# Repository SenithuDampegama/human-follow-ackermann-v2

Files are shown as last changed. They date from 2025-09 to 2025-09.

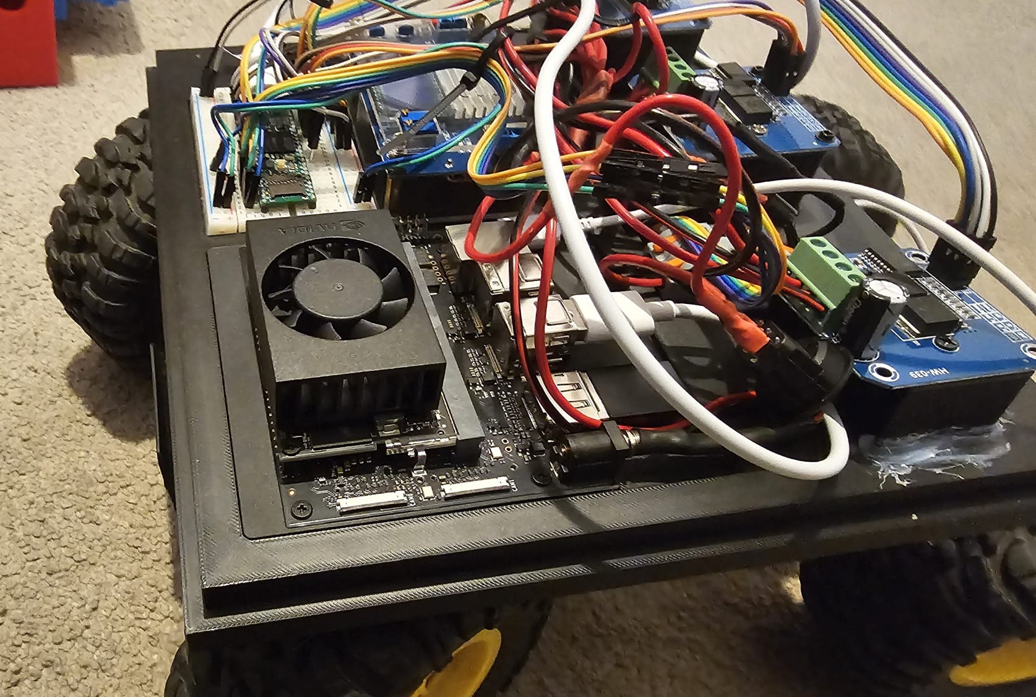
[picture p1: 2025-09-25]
media/Final component placement.jpeg

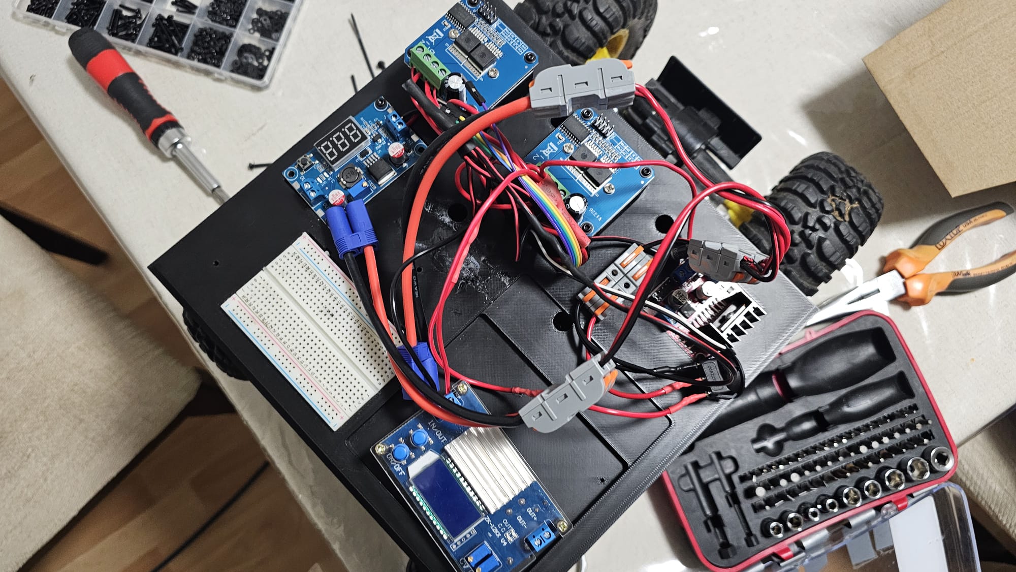
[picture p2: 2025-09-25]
media/assembling 1.jpeg

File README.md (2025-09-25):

# Human‑Following Ackermann v2 — OAK‑D Pro W

> **v2 of the human‑following Ackermann robot.** On‑camera perception with **OAK‑D Pro W** (Spatial MobileNet‑SSD), lightweight **IOU DeepSORT** tracking, and a robust layered control stack (L5 decision FSM on Jetson, L4 ASCII serial to Teensy 4.1). Safe **stationary SEARCH/RECOVER**, preview **RGB + Depth**, and runtime‑tunable steering.

---
Final_look

https://github.com/user-attachments/assets/c350c275-c0d9-4812-8b06-1a35ac1b5258
---

## ✨ Highlights
- **On‑device vision** (OAK‑D Pro W): RGB, StereoDepth (aligned), MobileNet **Spatial** detection (x,y,z in m)
- **Multi‑person lock:** IOU‑only DeepSORT tracker delivers stable `track_id`
- **Layered control:** L5 FSM (INIT→SEARCH→ACQUIRE→FOLLOW→FAULT) → L4 serial → Teensy drivers
- **Safety:** stationary SEARCH/RECOVER (no peeking), bounded runtime (`--max-seconds`), PWM caps
- **Robustness:** serial **auto‑reconnect** on USB drops; optional stable `/dev/teensy` symlink
- **Operator view:** dual preview **RGB + Depth** (scalable window), lock hotkeys `l/r`

---

## 🧱 Repository Layout
```
hf_ackermann/
  app.py                         # CLI entry (STUB/LIVE, OAKD/PINSIGHT/FAKE, tuning)
  control/
    rc_layer4.py                 # L4 serial client (ASCII, OK/DONE/TELEM, reconnect)
    rc_layer5.py                 # L5 decision FSM (stationary SEARCH), steering & distance
  vision/
    vision_oakd_onboard.py       # OAK‑D spatial NN + depth + composite preview
    vision_pinsight_legacy.py    # Legacy PiNSight adapter (fallback)
  tracking/
    deepsort_iou.py              # Lightweight IOU tracker (default)
    deepsort_heavy.py            # Optional wrapper for deep‑sort‑realtime
  tests/
    test_l4_smoke.py             # OK/DONE/TELEM smoke (auto‑skip if no Teensy)
    test_l4_fault.py             # L4 disconnect → auto‑reconnect (mocked)
  RC_firmware_simple/            # Embedded system code
    RC_firmware_simple.ino
    RcBasicCtr.cpp
    RcBasicCtr.h
    RcCompCtr.cpp
    RcCompCtr.h
    RcLinkSimple.cpp
    RcLinkSimple.h
scripts/
  run_stub_oakd.sh               # safe preview (no motion)
  run_live_oakd.sh               # hardware‑in‑loop (wheels‑up first!)
requirements.txt
README.md  (this)
LICENSE    (MIT)
```

---

## 🔧 Hardware
- **Compute:** NVIDIA Jetson (Orin Nano or better)
- **Camera:** OAK‑D Pro W (wide FOV, Myriad X)
- **MCU:** Teensy 4.1 (actuation & safety)
- **Drivers:** BTS7960 (drive), BTS7980 or equivalent (steering)
- **Power:** LiPo + protection; common ground; short, shielded USB to Teensy

> Tip: Keep OAK‑D and motor returns cleanly separated; ferrites on USB help.

---

## 🚀 Setup
```bash
python3 -m venv .venv && source .venv/bin/activate
pip install -r requirements.txt

# (optional) verify OAK‑D
python - <<'PY'
import depthai as dai
with dai.Device() as d:
    print('OAK-D connected:', d.getDeviceName(), d.getMxId())
PY

# serial permissions (Linux)
sudo usermod -aG dialout $USER && newgrp dialout
```

---

## ▶️ Quick Start
### Safe (STUB: no motion)
```bash
./scripts/run_stub_oakd.sh
# or
python -m hf_ackermann.app --mode STUB --vision OAKD --show 1 --max-seconds 8
```

### LIVE (hardware‑in‑loop)
> **Safety:** first runs **wheels‑up** on a stand.
```bash
./scripts/run_live_oakd.sh
# or, explicit port
python -m hf_ackermann.app --mode LIVE --vision OAKD --port /dev/ttyACM0 --show 1 --max-seconds 10
```

**Preview hotkeys:** `l` lock nearest, `r` release, `q/ESC` quit  
*(optional if enabled)* `s` STOP, `c` CENTER

---

## 🧭 Control & Protocols
**L5 FSM:** INIT → **SEARCH** → ACQUIRE → FOLLOW → FAULT  
- **SEARCH/RECOVER:** stationary (STOP + CENTER once), no motion until a valid target appears
- **FOLLOW:** steer by horizontal offset (non‑linear map); hold distance by **depth z** if available else **area**

**L4 (ASCII serial, unchanged):**
```
STOP
CENTER
DRIVE F <pwm> <ms>   | DRIVE B <pwm> <ms>
ARC   L <pwm> <ms> U | ARC R <pwm> <ms> U
```
Replies: `OK`, `DONE <ARC|DRIVE>`, `TELEM drive=… steer=… L=… R=… t=…` (≈5 Hz)

---

## ⚙️ CLI (selected flags)
```
--mode {STUB,LIVE}                --vision {OAKD,FAKE,PINSIGHT}
--port /dev/ttyACM0               --max-seconds 10
--show {0,1}                      --show-scale 0.5

# Steering (turn shaping)
--deadband-x 0.16                 --arc-gamma 1.6
--pwm-turn-min 140                --steer-bias 0.00
--k-arc-left 700  --k-arc-right 820
--cap-left 250    --cap-right 300
--impulse-left 180 --impulse-right 200

# Distance
--target-z 1.2                    # prefer depth (m)
--target-area 0.18 --area-tol 0.04 # fallback via bbox area
```

---

## 🧪 Tests
```bash
pytest -q hf_ackermann/tests   # lightweight unit tests (no hardware needed)
```

---

## 🛟 Safety & Troubleshooting
- Start in **STUB**, then LIVE **wheels‑up**.
- If serial drops mid‑run: system enters **FAULT**, auto‑reconnects, then resumes in SEARCH.
- Permission denied on `/dev/ttyACM*` → add user to `dialout` (see Setup).
- Choppy preview on Jetson → `--show 0` or lower `--show-scale`.

**Stable serial path (optional):** add udev rule for `/dev/teensy` symlink:
```
# /etc/udev/rules.d/99-teensy.rules
SUBSYSTEM=="tty", ATTRS{idVendor}=="16c0", ATTRS{idProduct}=="0483", SYMLINK+="teensy"
# then
sudo udevadm control --reload-rules && sudo udevadm trigger
```
Use with `--port /dev/teensy`.

---

## 🎛️ Tuning Cheatsheet
- **Right turns too soft?** Increase `--k-arc-right`, `--cap-right`, `--impulse-right`; raise `--pwm-turn-min`.
- **Oscillation?** Increase `--deadband-x` (+0.02) or lower `--arc-gamma` (→1.4–1.6).
- **Far off‑center response slow?** Raise `--arc-gamma` (e.g., 1.8).
- **Prefer depth‑first distance:** set `--target-z` (e.g., 1.2 m).

---

## 📄 License
MIT — see `LICENSE`.

## 🙏 Acknowledgements
DepthAI/OAK‑D (Luxonis), Jetson community, Teensy core devs.

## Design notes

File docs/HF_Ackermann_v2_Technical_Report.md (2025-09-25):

# Human-Following Ackermann v2 — OAK-D Pro W Refactor

Author: Senithu (University of Hertfordshire)

Date: 2025-09-23

## Table of Contents
- [Executive Summary](#executive-summary)
- [System Overview](#system-overview)
- [Hardware Summary](#hardware-summary)
- [Software Architecture](#software-architecture)
  - [Vision (OAK-D Onboard)](#vision-oak-d-onboard)
  - [Tracking](#tracking)
  - [L5 FSM (Decision Layer)](#l5-fsm-decision-layer)
  - [L4 Serial Client](#l4-serial-client)
- [Control Parameters](#control-parameters)
  - [Steering and Turn Shaping](#steering-and-turn-shaping)
  - [Distance and Motion](#distance-and-motion)
  - [Safety and Robustness](#safety-and-robustness)
- [Setup & Runbook](#setup--runbook)
- [Validation & Tests](#validation--tests)
- [Tuning Guide](#tuning-guide)
- [Known Limitations & Risks](#known-limitations--risks)
- [Future Work](#future-work)
- [Appendices](#appendices)
  - [A. CLI Flags](#a-cli-flags)
  - [B. Serial Protocol](#b-serial-protocol)
  - [C. Safety Checklist](#c-safety-checklist)

---

## Executive Summary
- Goal: Refactor into a production-ready human-following stack using OAK-D Pro W with on-camera MobileNetSpatialDetectionNetwork, an efficient IOU tracker, and a robust L5 controller targeting a Teensy-based drive system.
- Approach: On-camera spatial detections (RGB-aligned depth), lightweight IOU tracker for sticky IDs, L5 FSM with stationary SEARCH and decisive FOLLOW steering, and L4 serial client with robust auto-reconnect.
- Results: Stable target lock among multiple people, safe stationary SEARCH, decisive right turns via asymmetric tuning, and bounded runtime option for CI/smoke.
- Safety: Default STUB mode, capped drive PWM, stationary SEARCH/RECOVER, robust serial fault handling, and explicit wheels-up first-run guidance.
- Constraints: Layer-4 ASCII protocol unchanged; firmware unmodified; FSM maintained with enhancements (lock, z-based distance, stationary SEARCH).
- Extensibility: Optional heavy DeepSORT wrapper, configurable preview scaling, CLI-tunable steering shaping.

## System Overview
A modular pipeline runs OAK-D spatial detections, tracking, decision-making, and serial control.

```mermaid
flowchart LR
  A[OAK-D Pro W\nRGB + StereoDepth\nSpatial NN 300x300] --> B[Detections\n(bbox, conf, z_m)]
  B --> C[IOU Tracker\nStable Track IDs]
  C --> D[VisionBus\n(offset_x, area, quality,\ntrack_id, z_m)]
  D --> E[L5 FSM\nINIT→SEARCH→ACQUIRE→FOLLOW→FAULT]
  E --> F[L4 Serial Client]
  F --> G[Teensy L3 Firmware]
```

ASCII block (compatibility):

```
OAK-D (RGB, StereoDepth, Spatial NN)
       | detections (bbox, conf, z_m)
       v
  IOU Tracker  --> Track IDs
       v
  VisionBus (offset_x, area, quality, track_id, z_m)
       v
  L5 FSM (INIT→SEARCH→ACQUIRE→FOLLOW→FAULT)
       v
  L4 (ASCII serial)  ==USB==>  Teensy (L3)
```

Repository layout:

```
./hf_ackermann/
  app.py                      # CLI entry point
  control/
    rc_layer4.py              # L4 serial client (ASCII, OK/DONE, TELEM, reconnect)
    rc_layer5.py              # L5 FSM (stationary SEARCH, lock, depth distance, steering shaping)
  tracking/
    deepsort_iou.py           # lightweight IOU-based tracker
    deepsort_heavy.py         # optional wrapper (deep-sort-realtime)
  vision/
    vision_oakd_onboard.py    # OAK-D spatial NN + RGB/Depth composite preview
    vision_pinsight_legacy.py # legacy MobileNetSSD fallback (non-spatial)
  tests/
    test_l4_smoke.py
    test_l4_fault.py
    test_turn_gains.py
scripts/
  run_stub_oakd.sh
  run_live_oakd.sh
requirements.txt
README.md
```

## Hardware Summary
- Compute: NVIDIA Jetson (generic) or equivalent Linux SBC with USB3.
- Vision: Luxonis OAK-D Pro W (RGB + stereo IR + active illumination; wide FOV).
- MCU: Teensy 4.1 running Layer-3 firmware (ASCII serial protocol).
- Drivers/Actuation: e.g., BTS7960 H-bridge motor drivers; Ackermann steering.
- Power: Provide adequate isolation, brownout protection, and EMI mitigation (ferrite beads, star-grounding). Ensure powered USB hub if needed.
- Safety: First runs on a stand (wheels up). Confirm emergency stops. Avoid tether snags.

## Software Architecture

### Vision (OAK-D Onboard)
- Pipeline: ColorCamera (THE_1080_P) with ISP scaling → ImageManip (keepAspect) → MobileNetSpatialDetectionNetwork (300×300) with depth aligned to RGB via StereoDepth.
- Output per detection: bbox, confidence, label, spatialCoordinates → z_m = max(0, z_mm/1000).
- Preview: Composite RGB (annotated) | Depth (false-color TURBO), optional scaling `--show-scale` (default 0.6). Hotkeys: `l` lock nearest, `r` release, `q`/ESC quit.
- Robustness: Stereo preset resolved across DepthAI versions; logs DepthAI version and device MXID.

### Tracking
- IOU-only tracker (deepsort_iou.py): greedy IOU assignment, `max_age`, `min_hits`, and `iou_threshold`. Monotonic, sticky IDs. Low-CPU.
- Optional heavy wrapper (deepsort_heavy.py) if `deep-sort-realtime` is installed; same `.update()` API.

### L5 FSM (Decision Layer)
- States: INIT → SEARCH → ACQUIRE → FOLLOW → FAULT.
- SEARCH/RECOVER: Stationary. On entry, STOP + CENTER once; no arcs or nudges until a confident target appears.
- FOLLOW Steering: Non-linear mapping from offset_x to PWM with tunable exponent `arc_gamma`, minimum PWM, and asymmetric gains/caps/impulses (right-biased by default). Cooldown gated locally (not passed into L4).
- Distance Control: Prefer depth `z_m` toward `target_z_m` (with `z_tol_m` band). If depth unavailable, hold via area setpoint (`target_area`, `area_tol`).
- Target Lock: If a `locked_id` is set, only measurements with that track_id are considered valid; public `lock_target(track_id)`/`release_lock()`.
- Fault Handling: Catch `L4Disconnected`, enter FAULT, stop issuing motion, and attempt reconnect with exponential backoff. On success: STOP + CENTER (resync), clear lock, transition to SEARCH.

### L4 Serial Client
- Protocol (unchanged): Uppercase ASCII commands
  - `STOP`, `CENTER`, `STEER L/R/U`, `DRIVE F/B <pwm> <ms>`, `ARC L/R <pwm> <ms> <U|H>`
  - Replies: `OK <TAG>`, `DONE <ARC|DRIVE>`, `ERR ...`; TELEM lines (e.g., `TELEM drive=.. steer=.. L=.. R=.. t=..`).
- IO: 115200 baud, `timeout≈0.05s`, `ACK timeout≈2s`, DONE wait ≥ max(duration+2.5s, 6s). Auto-detect port preferring “Teensy”.
- Robustness: Catches serial exceptions, marks disconnected, and exposes `_reopen()` to re-establish link and resync.

## Control Parameters

### Steering and Turn Shaping
Defaults (HFParams in `rc_layer5.py`) and CLI overrides (see Appendix):

| Parameter | Default | Description |
|---|---:|---|
| deadband_x | 0.16 | No-steer window on |offset_x| |
| arc_gamma | 1.6 | Exponent shaping for turn intensity |
| pwm_turn_min | 140 | Minimum PWM when issuing a turn |
| k_arc_pwm_left | 700 | Left turn gain |
| k_arc_pwm_right | 820 | Right turn gain (bias to the right) |
| arc_pwm_cap_left | 250 | Left PWM cap |
| arc_pwm_cap_right | 300 | Right PWM cap |
| arc_impulse_ms_left | 180 ms | Left arc impulse duration |
| arc_impulse_ms_right | 200 ms | Right arc impulse duration |
| steer_bias | 0.00 | Static bias (+ shifts to right) |
| cooldown_ms | 90 | Local cooldown after actuation |

### Distance and Motion

| Parameter | Default | Description |
|---|---:|---|
| target_z_m | None | Desired meter range (if set, prefer depth) |
| z_tol_m | 0.15 m | Tolerance band around `target_z_m` |
| target_area | 0.18 | Desired bbox area fraction (fallback) |
| area_tol | 0.04 | Tolerance band for area control |
| k_drive_pwm | 2200 | Drive aggression toward setpoint |
| min_drive_pwm | 120 | Minimum forward PWM |
| max_drive_pwm | 190 (HFParams) / 250 (app default) | Forward PWM cap |
| drive_impulse_ms | 240 ms | Forward impulse duration |
| close_back_pwm | 140 | Reverse PWM when too close |
| close_back_ms | 150 ms | Reverse impulse duration |

### Safety and Robustness

| Parameter | Default | Description |
|---|---:|---|
| loop_hz | 15.0 | L5 control loop rate |
| stale_ms | 300 ms | Stale vision age threshold |
| lost_ms | 700 ms | Time without fresh target to declare loss |
| reconnect backoff | 1→2→4→8→10 s | Exponential backoff in FAULT |
| bounded runtime | `--max-seconds` | Clean exit for CI/smoke runs |

## Setup & Runbook

Environment:

```bash
python -m venv .venv && source .venv/bin/activate
pip install -r requirements.txt
```

OAK-D probe (bounded):

```python
# Quick import check (≤5 s)
from hf_ackermann.vision.vision_oakd_onboard import OAKDSpatial
print("OAKD module import OK")
```

Run commands (examples):

```bash
# STUB (safe; no motion)
python -m hf_ackermann.app --mode STUB --vision OAKD --show 1 --max-seconds 10

# LIVE (Teensy connected; wheels-up)
python -m hf_ackermann.app --mode LIVE --vision OAKD --show 1 --max-seconds 10

# Smaller preview window
python -m hf_ackermann.app --mode STUB --vision OAKD --show 1 --show-scale 0.6 --max-seconds 10
```

## Validation & Tests
- STUB + OAK-D: Observe INIT → SEARCH (stationary STOP+CENTER), then ACQUIRE/FOLLOW when a person enters. Confirm target lock stability among multiple people.
- LIVE (wheels-up): TELEM ~5 Hz; steering/drive impulses within caps; no movement in SEARCH.
- Disconnect/Reconnect: Unplug Teensy during operation → FAULT; logs periodic reconnect attempts, resyncs on success (STOP+CENTER), resumes SEARCH.
- Depth vs Area: With `--target-z` set, verify distance holds using depth; otherwise area-based setpoint.

## Tuning Guide
- Boost right turns:

```bash
--k-arc-right 900 --cap-right 320 --impulse-right 220 --arc-gamma 1.7 --pwm-turn-min 150
```

- Reduce oscillation:
  - Increase `deadband_x` slightly (e.g., 0.18–0.20).
  - Lower `arc_gamma` toward linear (e.g., 1.2–1.4) or reduce gains/caps proportionally.
- Depth jitter:
  - Increase `tau_z_ms` or widen `z_tol_m`.
  - Ensure good lighting/texture; avoid reflective/transparent surfaces.

## Known Limitations & Risks
- Open-loop motion (no encoders): true speed/heading not closed-loop; drift possible.
- Lighting/Depth edge cases: specular/low-texture surfaces can degrade depth.
- Tracker ID swaps: rare with IOU-only; embeddings (heavy) can help when available.
- EMI/USB reliability: mitigate with ferrites and quality cabling; auto-reconnect in software.

## Future Work
- Appearance embeddings with heavy DeepSORT; adaptive association.
- Systemd unit for unattended startup; watchdog monitoring.
- Web UI/telemetry (stream logs, preview, tuning sliders).
- Stable `/dev/teensy` symlink via udev for consistent port naming.

## Appendices

### A. CLI Flags
Extracted from `hf_ackermann/app.py` (defaults shown):

| Flag | Type | Default | Description |
|---|---|---|---|
| --mode | {STUB, LIVE} | STUB | Operating mode |
| --vision | {OAKD, FAKE, PINSIGHT} | OAKD | Vision source |
| --port | str | None | Serial port (auto-detect if None) |
| --fps | int | 30 | Camera FPS |
| --loop-hz | float | 15.0 | L5 loop rate |
| --show | int | 1 | Show preview (1/0) |
| --conf | float | 0.5 | Detection confidence threshold |
| --blob | str | None | MobileNet-SSD blob path (optional) |
| --use-tracker | {iou, heavy} | iou | Tracker implementation |
| --target-area | float | 0.18 | Area setpoint (fallback) |
| --target-z | float | None | Depth setpoint (meters) |
| --verbose | int | 1 | Verbose logging |
| --depth-range | str | "0.3,4.0" | Depth viz near,far (meters) |
| --show-scale | float | 0.6 | Preview display scale |
| --max-seconds | float | None | Bounded runtime for CI/smoke |
| --arc-gamma | float | 1.6 | Non-linearity exponent for \|offset_x\| |
| --pwm-turn-min | int | 140 | Minimum PWM when turning |
| --k-arc-left | int | 700 | Left turn gain |
| --k-arc-right | int | 820 | Right turn gain |
| --cap-left | int | 250 | Left PWM cap |
| --cap-right | int | 300 | Right PWM cap |
| --impulse-left | int | 180 | Left impulse duration (ms) |
| --impulse-right | int | 200 | Right impulse duration (ms) |
| --steer-bias | float | 0.0 | Static bias (+ right) |

### B. Serial Protocol
Examples (ASCII over 115200 baud):

```
Host → Teensy:  DRIVE F 180 1200\n
Teensy → Host:  OK DRIVE
...
Teensy → Host:  DONE DRIVE

Host → Teensy:  ARC R 200 700 U\n
Teensy → Host:  OK ARC
...
Teensy → Host:  DONE ARC

Teensy → Host (async): TELEM drive=0 steer=1 L=123 R=456 t=789012
```

### C. Safety Checklist
- [ ] First power-on with wheels up on a stand.
- [ ] Serial port auto-detected; verify `TELEM` at ~5 Hz in LIVE.
- [ ] Confirm `--show 1` preview overlays and depth composite.
- [ ] Verify stationary SEARCH (no motion until target appears).
- [ ] Confirm forward PWM caps are reasonable for environment.
- [ ] Keep emergency stop within immediate reach.

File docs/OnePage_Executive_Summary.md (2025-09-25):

# One-Page Executive Summary — Human-Following Ackermann v2 (OAK-D Pro W)

Author: Senithu (University of Hertfordshire)  
Date: 2025-09-23

## Overview
This project refactors a human-following Ackermann robot into a clean, production-ready stack centered on the Luxonis OAK-D Pro W. It uses on-camera MobileNetSpatialDetectionNetwork for person detection with depth, a lightweight IOU tracker for stable IDs, and a robust decision layer (L5) that commands a Teensy-based drive via an ASCII serial protocol (L4). The system prioritizes safety (stationary SEARCH mode, capped motion) and reliability (serial auto-reconnect), with runtime-tunable steering and a compact RGB+Depth preview.

## Architecture
- OAK-D Pro W: RGB + StereoDepth aligned to RGB, MobileNet spatial NN (300×300).  
- Tracking: IOU-only tracker with greedy IOU matching; stable, monotonic IDs.  
- L5 FSM: INIT → SEARCH → ACQUIRE → FOLLOW → FAULT. SEARCH is stationary (STOP + CENTER once), FOLLOW uses a non-linear steering model with asymmetric left/right gains and caps; distance uses depth `z_m` if available, else bbox area.  
- L4 Serial: Uppercase ASCII commands (`STOP`, `CENTER`, `DRIVE`, `ARC`, `STEER`) with OK/DONE waits and TELEM parsing. Robust auto-reconnect after transient drops.

## Key Features
- Stationary SEARCH/RECOVER: No motion until a confident target reappears.  
- Decisive steering: Tunable non-linear mapping; asymmetric right-turn boost.  
- Safety: STUB default mode, capped motion, wheels-up first run.  
- Robustness: Serial disconnect handling with exponential backoff and resync.  
- Preview: Side-by-side RGB (annotated) + false-color Depth; `--show-scale` for display size.

## How to Run (Examples)
- STUB (safe; 10s bounded):
```
python -m hf_ackermann.app --mode STUB --vision OAKD --show 1 --max-seconds 10
```
- LIVE (wheels-up; bounded):
```
python -m hf_ackermann.app --mode LIVE --vision OAKD --show 1 --max-seconds 10
```
- Smaller preview window:
```
python -m hf_ackermann.app --mode STUB --vision OAKD --show 1 --show-scale 0.6 --max-seconds 10
```

## Steering Tuning (Runtime Flags)
- Non-linearity and minimum: `--arc-gamma 1.6 --pwm-turn-min 140`
- Asymmetry (right-biased defaults):
```
--k-arc-right 820 --cap-right 300 --impulse-right 200 \
--k-arc-left 700  --cap-left 250  --impulse-left 180
```
- Example right-turn boost:
```
--k-arc-right 900 --cap-right 320 --impulse-right 220 --arc-gamma 1.7 --pwm-turn-min 150
```

## Validation
- STUB: INIT → stationary SEARCH; ACQUIRE/FOLLOW engage when a person enters; lock persists across multi-person scenes.  
- LIVE: TELEM ~5 Hz; capped impulses; no motion in SEARCH.  
- Faults: USB drop → FAULT; periodic reconnect; resync (STOP+CENTER); resume SEARCH.

## Risks & Next Steps
- Risks: Open-loop motion without encoders; depth edge cases (reflective/low-texture surfaces); occasional ID swaps with IOU-only tracking.  
- Next: Optional heavy DeepSORT (embeddings), systemd service for autostart, udev rule for stable `/dev/teensy`, telemetry UI.

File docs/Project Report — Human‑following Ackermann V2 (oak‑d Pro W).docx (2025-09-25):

# Human‑Following Ackermann v2 — Refactor to OAK‑D Pro W

Author: Senithu Dampegama — Robotics & AI Engineer
Date: 23 September 2025
Version: v2 (successor to the Arducam/PiNSight-based v1)

## 0) Executive Summary

- Objective: Upgrade the prior human‑following Ackermann robot (v1) to reliably track one person among many while reducing Jetson load.
- Approach: Offload perception to OAK‑D Pro W (Myriad X) running a Spatial MobileNet‑SSD; add a lightweight IOU DeepSORT tracker; retain the proven L5/L4 layered control with Teensy 4.1 actuation.
- Safety & Robustness: Stationary SEARCH/RECOVER (no motion), serial auto‑reconnect on USB drops, bounded runtime flag for tests, capped PWM, and scalable dual preview (RGB + Depth).
- Results: Stable person lock with low Jetson usage; tighter right turns via asymmetric steering gains and non‑linear mapping; unchanged ASCII protocol to Teensy; clean STUB→LIVE runbooks.
- Deliverables: A reorganized package hf_ackermann/ ready for reuse, plus this report documenting architecture, parameters, tests, and future work.

## 1) Background & Motivation

v1 summary. The previous build transformed a failed RC toy into a research robot: Jetson Orin Nano for perception/decision (L5), Teensy 4.1 for actuation/safety (L3), and a simple ASCII protocol (L4). It followed a single person reliably but could not lock onto one human if multiple people entered the frame.

v2 goals. 1. Resolve multi‑person ambiguity via per‑person IDs.
2. Reduce Jetson load by moving heavy CV to the vision sensor.
3. Preserve the safe, layered control split and the exact L4 ASCII protocol to avoid firmware churn.

Key change: Replace Arducam/PiNSight with OAK‑D Pro W; implement a lightweight, IOU‑only DeepSORT to keep stable track_id while minimizing compute.

## 2) System Architecture (L5→L1)

OAK‑D Pro W ── RGB + StereoDepth + Spatial NN (on‑device)
│ detections {bbox, conf, z_mm}
▼
Tracking (IOU DeepSORT) → selected target {track_id, offx, area, z_m, quality}
▼
L5 (Jetson) Decision FSM INIT → SEARCH → ACQUIRE → FOLLOW → FAULT
│ emits high‑level actions (ARC/DRIVE/STOP/CENTER)
▼
L4 (Jetson) ASCII Serial Client → Teensy 4.1 (safety, PWM bursts, stall guard)
▼
Drivers & Actuators (BTS7960 drive, BTS7980 steering)

What’s new in v2 - On‑device Spatial NN (x,y,z) from OAK‑D; Jetson only does tracking + L5.
- Dual preview: RGB with overlays + depth false‑color (scalable).
- Stationary SEARCH/RECOVER (no peeking) for safety and clarity.
- Asymmetric steering (right boosted) and gamma‑shaped turn mapping.
- Serial auto‑reconnect & bounded runtime for robust testing.

## 3) Hardware Overview

- Compute: NVIDIA Jetson (Orin Nano or better).
- Camera: OAK‑D Pro W (wide FOV), Myriad X.
- Controller: Teensy 4.1 (Cortex‑M7, 600 MHz).
- Drivers: BTS7960 (drive axles), BTS7980 (steering).
- Power: Dual 3S LiPo, separate regulators; common ground; shielded USB to Teensy.

Note: Keep OAK‑D and high‑current returns cleanly separated; add ferrites to USB if needed.

## 4) Software Architecture

### 4.1 Vision (OAK‑D On‑Device)

- Pipeline: ColorCamera 1080p + StereoDepth (aligned to RGB) → MobileNetSpatialDetectionNetwork @ 300×300.
- Outputs per detection: bbox_px, confidence, label, spatialCoordinates.{x,y,z} in mm.
- VisionBus payload to L5: {track_id, offx∈[-1..1], area∈[0..1], quality, z_m (m), ts}.
- Preview (when enabled): Composite window [RGB annotated | Depth false‑color], scalable via --show-scale.
- Hotkeys: l lock nearest, r release, q/ESC quit (optional s STOP, c CENTER if wired).

### 4.2 Tracking (Lightweight DeepSORT)

- IOU‑only association with max_age, iou_threshold, hit_streak → sticky IDs at minimal compute cost.
- Optional heavy wrapper (deep‑sort‑realtime) available but off by default on Jetson.

### 4.3 Decision (L5) — FSM

States: INIT → SEARCH → ACQUIRE → FOLLOW → FAULT - SEARCH / RECOVER: stationary; on entry: STOP + CENTER once; wait for a valid target.
- ACQUIRE: quick steering impulses to bring target toward center; short forward nudges if far.
- FOLLOW: - Steering: non‑linear mapping from |offx| with exponent arc_gamma and a minimum turn PWM; asymmetric left/right gains & caps (right boosted).
- Distance: prefer depth z_m (target‑z), else area (target‑area ± tol).
- FAULT: triggered by L4 disconnects; L5 stops issuing motion, then attempts auto‑reconnect with backoff; on success: STOP + CENTER and resume SEARCH.

### 4.4 Interface (L4) — ASCII Protocol (unchanged)

- Commands: STOP, CENTER, DRIVE F|B <pwm> <ms>, ARC L|R <pwm> <ms> <U|H>.
- Replies: OK, DONE <ARC|DRIVE>, ERR <…>, TELEM drive=<…> steer=<…> L=<…> R=<…> t=<…>.
- Timing: 115200 baud; read timeout ≈ 0.05 s; cmd timeout ≈ 2 s; DONE timeout ≈ 3 s (or by duration).
- Robustness: auto‑detect Teensy; auto‑reconnect on SerialException; resume in SEARCH.

## 5) Repository Layout (v2)

hf_ackermann/
app.py # CLI entry: STUB/LIVE, vision source, tuning flags
control/
rc_layer4.py # L4 serial client (ASCII, OK/DONE/TELEM, reconnect)
rc_layer5.py # L5 FSM (stationary SEARCH), steering shaping, distance logic
vision/
vision_oakd_onboard.py # OAK‑D spatial NN + depth + composite preview
vision_pinsight_legacy.py # Legacy fallback (non‑spatial)
tracking/
deepsort_iou.py # Lightweight IOU tracker (default)
deepsort_heavy.py # Optional wrapper for deep‑sort‑realtime
tests/
test_l4_smoke.py # OK/DONE/TELEM smoke
test_l4_fault.py # L4 disconnect → auto‑reconnect (mocked)
scripts/
run_stub_oakd.sh # safe preview, no motion
run_live_oakd.sh # hardware‑in‑loop (wheels‑up first!)
requirements.txt, README.md, LICENSE

## 6) Interfaces & Protocols

### 6.1 Command Protocol (Jetson → Teensy)

STOP\n
CENTER\n
DRIVE F 190 240\n
DRIVE B 140 150\n
ARC L 220 180 U\n
ARC R 220 180 U\n

### 6.2 Telemetry Protocol (Teensy → Jetson)

OK\n
DONE DRIVE\n
TELEM drive=1 steer=2 L=497 R=1022 t=25090824\n

drive/steer are state codes; L/R are sensor counts; t is uptime ms.

## 7) Control Parameters (defaults)

### 7.1 Steering & Turn Shaping

Parameter | Default | Purpose
deadband_x | 0.16 | Ignore small offsets to avoid chatter
arc_gamma | 1.6 | Non‑linear turn shaping for large errors
pwm_turn_min | 140 | Enforce decisive minimum turn
k_arc_pwm_left | 700 | Left turn gain
k_arc_pwm_right | 820 | Right turn boosted
arc_pwm_cap_left | 250 | Max left arc PWM
arc_pwm_cap_right | 300 | Max right arc PWM
arc_impulse_ms_left | 180 ms | Left arc duration
arc_impulse_ms_right | 200 ms | Right arc duration
steer_bias | 0.00 | Optional static offset (normalize drift)

### 7.2 Distance & Motion

Parameter | Default | Purpose
target_z_m | (off) | Preferred distance (m) if depth available
target_area | 0.18 | Fallback distance via bbox area
area_tol | 0.04 | Area band around target
k_drive_pwm | 2200 | Forward PWM gain (capped)
max_drive_pwm | 190 | Safety cap for drive
drive_impulse_ms | 240 ms | Forward impulse duration
back_pwm | 140 | Reverse PWM for back‑off
back_impulse_ms | 150 ms | Reverse impulse duration

### 7.3 Robustness

Parameter | Default | Notes
search_mode | idle | SEARCH/RECOVER are stationary
--show-scale | 0.5–0.6 | Smaller preview window
--max-seconds | (off) | Bounded runtime for tests

All are exposed via CLI flags in app.py for runtime tuning.

## 8) Setup & Runbook

### 8.1 Environment

python3 -m venv .venv && source .venv/bin/activate
pip install -r requirements.txt

OAK‑D probe

python - <<'PY'
import depthai as dai
with dai.Device() as d:
print('OAK-D connected:', d.getDeviceName(), d.getMxId())
PY

### 8.2 STUB (safe, no motion)

./scripts/run_stub_oakd.sh
# or
python -m hf_ackermann.app --mode STUB --vision OAKD --show 1 --max-seconds 8

### 8.3 LIVE (hardware‑in‑loop)

Safety: first runs wheels‑up on a stand; ensure serial permissions (dialout).

./scripts/run_live_oakd.sh
# or
python -m hf_ackermann.app --mode LIVE --vision OAKD --show 1 --max-seconds 10

If auto‑detect fails: --port /dev/ttyACM0 (or a udev symlink /dev/teensy).

## 9) Validation & Observations

- Stationary SEARCH: verified — no ARC/DRIVE while waiting; transitions to ACQUIRE on fresh target.
- FOLLOW: decisive turns, especially to the right (boosted gains/caps); depth‑preferred distance with smooth back‑off when close.
- Serial robustness: induced disconnects yield [FAULT] → auto‑reconnect → STOP + CENTER → back to SEARCH without crash.
- Multi‑person: lock persists via track_id; l/r hotkeys control target selection.

Representative telemetry

TELEM drive=1 steer=2 L=497 R=1022 t=25090824
[FOLLOW] steer arcright pwm=220
TELEM drive=1 steer=2 L=526 R=1021 t=25091024
[FOLLOW] stale → center once
...

## 10) Risk & Limitations

- No wheel encoders → open‑loop velocity; rely on depth/area and impulses.
- Donor wiring caps drive PWM to 190 for thermal safety; revisit after loom upgrade.
- IOU‑only tracker can ID‑swap under heavy, long occlusions (lock + stationary SEARCH mitigates most cases).
- Depth noise possible in strong sun/low‑texture scenes; consider median filtering or depth caps.

## 11) Tuning Guide

- Right turns weak? Increase --k-arc-right, --cap-right, --impulse-right; optionally raise --pwm-turn-min and --arc-gamma.
- Over‑steer/oscillation? Increase --deadband-x by +0.02 or lower --arc-gamma (1.4–1.6).
- Far off‑center? Increase --arc-gamma (e.g., 1.8) and/or --pwm-turn-min.
- Depth‑first following: set --target-z 1.2 (example), otherwise use --target-area/--area-tol.

## 12) Future Work

- Appearance embeddings (heavy DeepSORT) when compute budget allows.
- Add encoders + basic odometry; consider SLAM for navigation.
- Wiring/driver upgrades to lift PWM caps safely.
- systemd auto‑start (STUB by default), simple web telemetry, and a udev rule for /dev/teensy.

## Appendix A — CLI Flags (selected)

--mode {STUB,LIVE}
--vision {OAKD,FAKE,PINSIGHT}
--port /dev/ttyACM0
--show {0,1} --show-scale 0.5
--max-seconds 10

# Steering & distance
--deadband-x 0.16
--arc-gamma 1.6
--pwm-turn-min 140
--k-arc-left 700 --k-arc-right 820
--cap-left 250 --cap-right 300
--impulse-left 180 --impulse-right 200
--steer-bias 0.00
--target-z 1.2
--target-area 0.18 --area-tol 0.04

## Appendix B — Serial Protocol Examples

> ARC R 220 180 U
< OK
< DONE ARC

> DRIVE F 190 240
< OK
< DONE DRIVE

< TELEM drive=1 steer=2 L=615 R=1022 t=25091724

## Appendix C — Safety Checklist

- Start in STUB; only then run LIVE (wheels‑up).
- Use --max-seconds during tests to avoid endless runs.
- Confirm TELEM rate (~5 Hz), caps (max_drive_pwm, arc_pwm_cap_*).
- Verify auto‑reconnect path by briefly replugging USB (observe FAULT→recover).
- Keep grounds clean; use short, shielded USB.

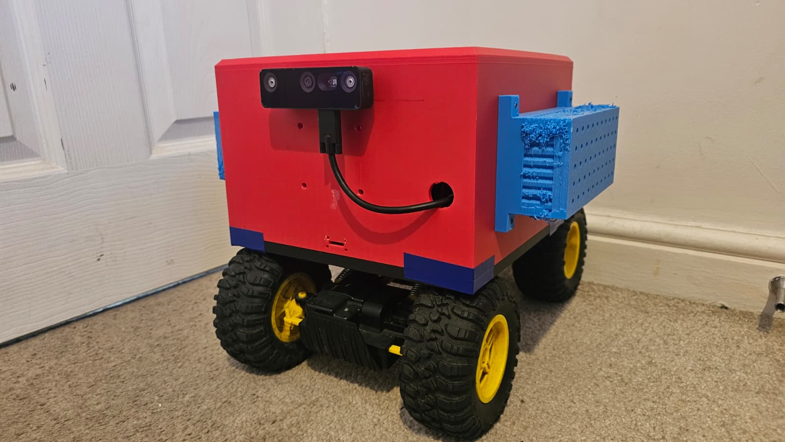
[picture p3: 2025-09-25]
media/front2.jpeg

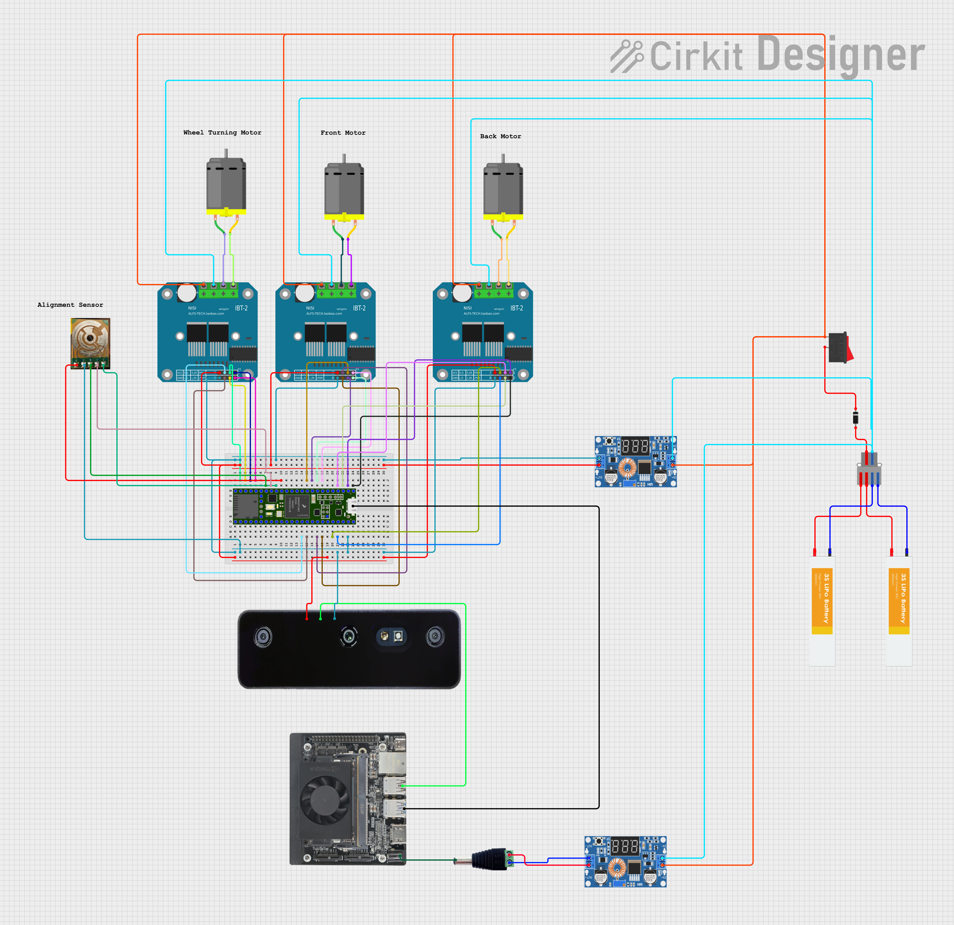
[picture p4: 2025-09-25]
docs/circuit_image.png

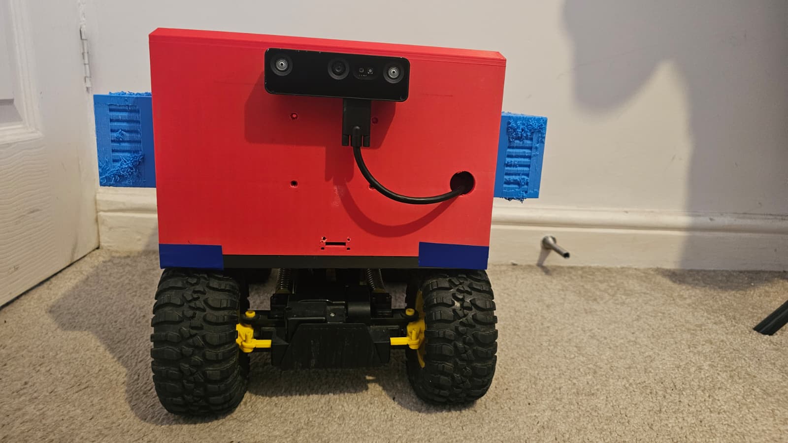
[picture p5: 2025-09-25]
media/front.jpeg

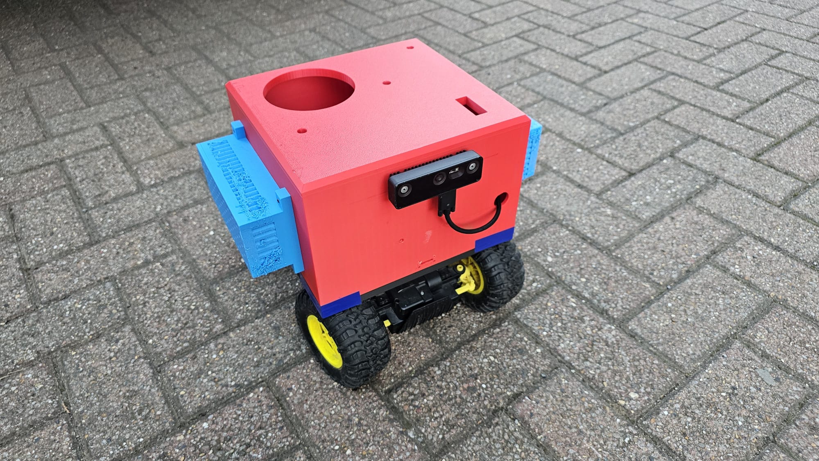
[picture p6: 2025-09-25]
media/Final_look.jpeg

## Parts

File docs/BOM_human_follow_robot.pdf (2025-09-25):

# Bill of Materials — Human‑Following Ackermann

v2

Item | Part Name | Description / Specs | Qty | Supplier /
| | | | Part No. | Notes
E1 | Teensy 4.1 | 600 MHz ARM Cortex-
| | M7 MCU, 55 I/O pins | 1 | PJRC | Main controller
| | | | | (Layer 1–3)
E2 | Jetson Orin Nano
| 8GB Dev Kit | 1024-core GPU, 8GB
| | RAM, AI compute | 1 | NVIDIA | Vision & AI
| | | | | processing
E3 | Motor Driver –
| BTS7960 | 43 A high-power H-
| | bridge | 2 | Amazon /
| | | | eBay | Front & rear drive
E4 | Motor Driver –
| BTS7980 | 55 A high-power H-
| | bridge | 1 | Amazon /
| | | | eBay | Steering control
E5 | OAK-D Pro Wide | USB AI camera module | 1 | Luxonis | Runs vision
| | | | | pipeline
E6 | LiPo Battery 3S 11.1V
| (≥5000 mAh) | Main power source | 2 | Hobby store | Power for drive &
| | | | | compute
E7 | Buck Converter
| (12V→5V, 5A) | Power regulation | 2 | Amazon | Jetson &
| | | | | peripherals
E8 | Step-Down Regulator
| (12V→7.4V) | Steering driver supply | 1 | Amazon | Clean supply for
| | | | | steering
E9 | XT60 Connectors +
| Harness | High-current connectors | 6 | Amazon | Power distribution
E10 | 12 AWG Silicone Wire
| (red/black) | High-current wiring | 5 | Amazon | Drive power loom
E11 | 18 AWG Wire (signal) | Low-current wiring | 10 | Amazon | Signals/logic
E12 | Inline Fuse Holder +
| Fuses | Protection | 2 | Amazon | Battery safety
E13 | Ferrite USB-C Bead | EMI suppression | 2 | Amazon | Teensy/OAK-D
| | | | | USB
E14 | USB-C Cable (short,
shielded) | Data + power for OAK-D | 1 | Anker | Prefer 0.5 m shielded

1

Item | Part Name | Description / Specs | Qty

Supplier /
Part No.

Notes

E15

USB Micro/Type-A
Cable (shielded) | Teensy connection | 1 | Anker | Short, shielded

E16

Chassis Mounts &

Brackets | Mechanical mounts | 1 | Custom | 3D prints /
| | | | aluminum

E17

Wheels/Tracks

(Ackermann) | Locomotion | 4 | Donor RC | Usable donor
| | | | parts

E18

Current Sensor

(optional) | Stall monitoring | 2 | Pololu | Firmware support
| | | | optional

E19

RC Kill Switch
(optional) | Emergency stop | 1 | Spektrum | Safety accessory
E20 | Misc. Hardware | Screws, standoffs,
| heatshrink | 1 | — | Build
| | | | consumables

Note: Quantities and suppliers reflect the reference build; adjust to your inventory.

2

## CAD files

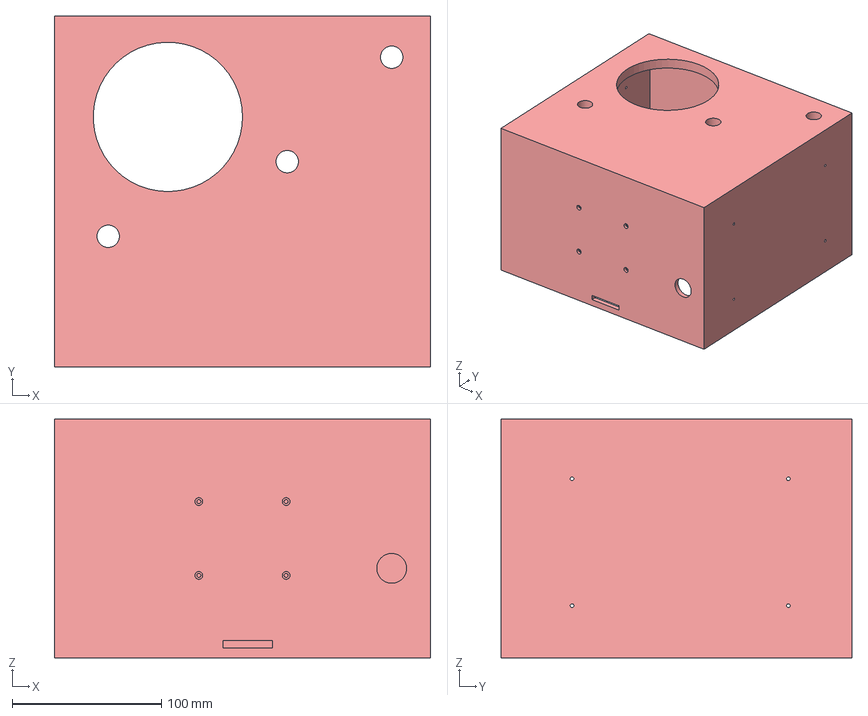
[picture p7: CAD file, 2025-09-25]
cad/Main_Lid.step
252.0 x 235.0 x 160.0 mm

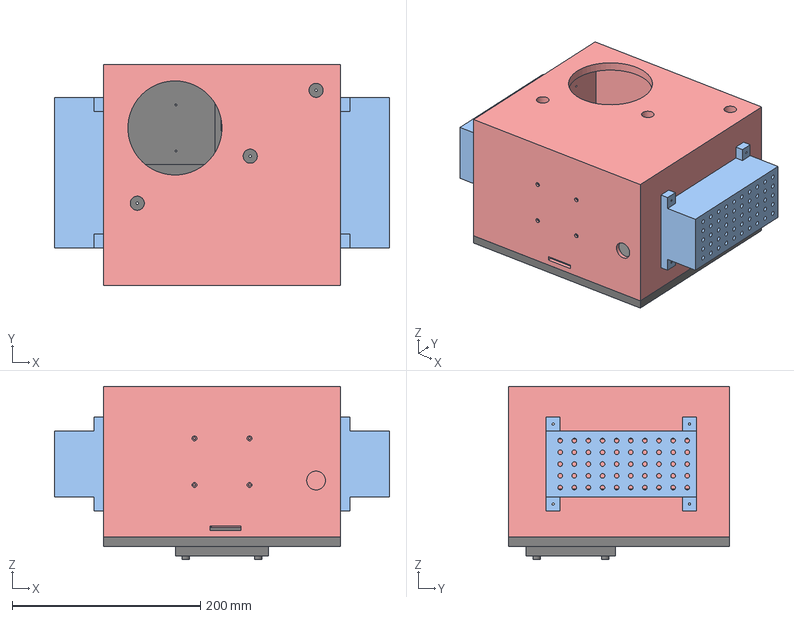
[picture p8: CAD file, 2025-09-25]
cad/Assembly.step
356.0 x 235.0 x 184.0 mm
battery lid x 2
Base
main lid

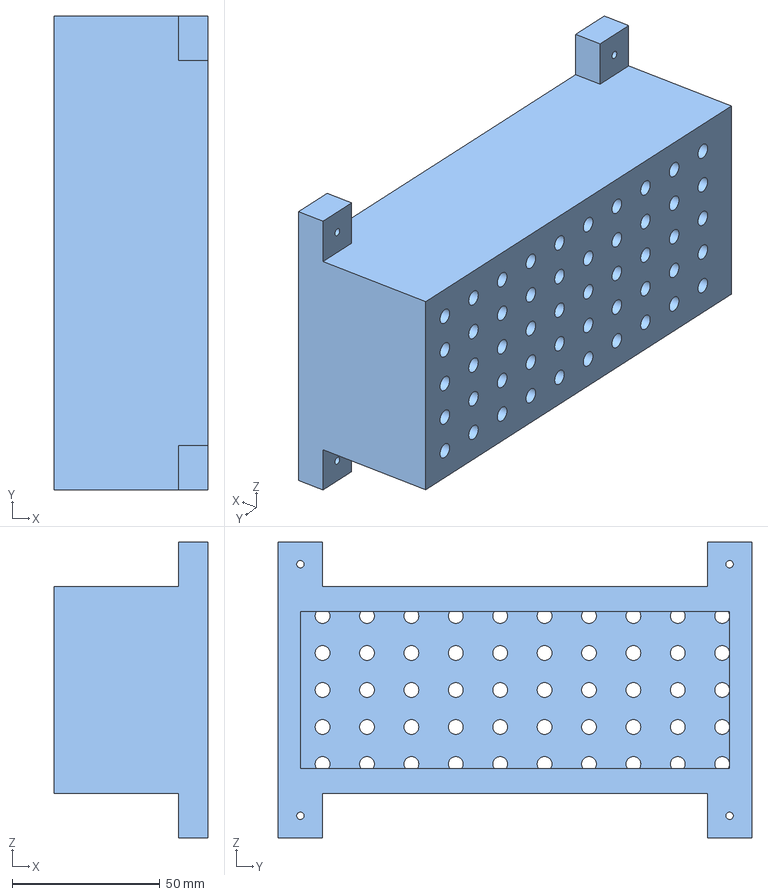
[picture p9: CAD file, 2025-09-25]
cad/Battery_Lid.step
52.0 x 160.0 x 100.0 mm

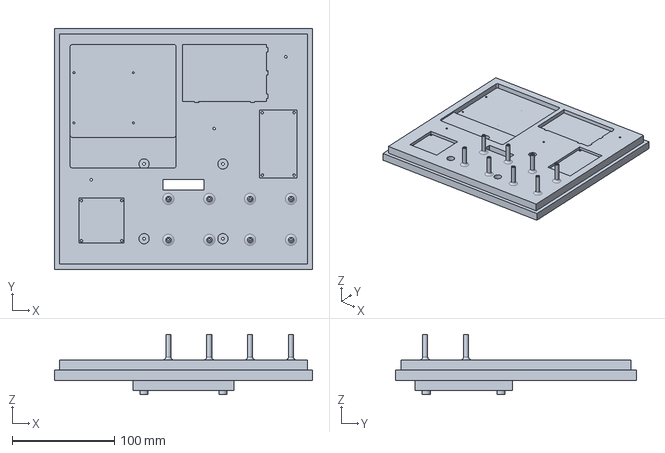
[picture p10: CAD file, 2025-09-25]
cad/Base.step
252.0 x 235.0 x 59.0 mm

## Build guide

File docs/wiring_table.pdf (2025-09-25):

# Wiring Table — Human Follow Robot

Controller: Teensy 4.1
Power: Dual LiPo → Buck Converters → Logic & Jetson

## Front Axle — Motor Drivers (BTS7960)

Pin | Signal | Destination Pin
5 | FL_PWM | PWM-L
6 | FR_PWM | PWM-R
7 | FL_EN | EN-L
8 | FR_EN | EN-R
A6 | FL_IS | IS-L
A5 | FR_IS | IS-R

## Rear Axle — Motor Drivers (BTS7960)

Pin | Signal | Destination Pin
0 | BL_PWM | PWM-L
1 | BR_PWM | PWM-R
2 | BL_EN | EN-L
3 | BR_EN | EN-R
A9 | BL_IS | IS-L
A8 | BR_IS | IS-R

## Steering — Motor Driver (BTS7980)

Pin | Signal | Destination Pin
28 | TL_PWM | PWM-L
29 | TR_PWM | PWM-R
30 | TL_EN | EN-L
31 | TR_EN | EN-R
A3 | TL_IS | IS-L
A2 | TR_IS | IS-R

## Wheel Alignment Sensor

Pin | Signal | Destination
A10 | Left | Alignment Sensor Left Output
A11 | Middle | Alignment Sensor Middle Output

A12 | Right | Alignment Sensor Right Output

## Power & Comms

Pin | Signal | Destination
VIN | +Vcc | 5 V Logic rail from buck converter
GND | Ground | Common GND to all modules
USB | Data | Jetson Orin Nano

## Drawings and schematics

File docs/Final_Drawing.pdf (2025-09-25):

A

2 | 3 | 4 | 5 | 6 | 7 | 8

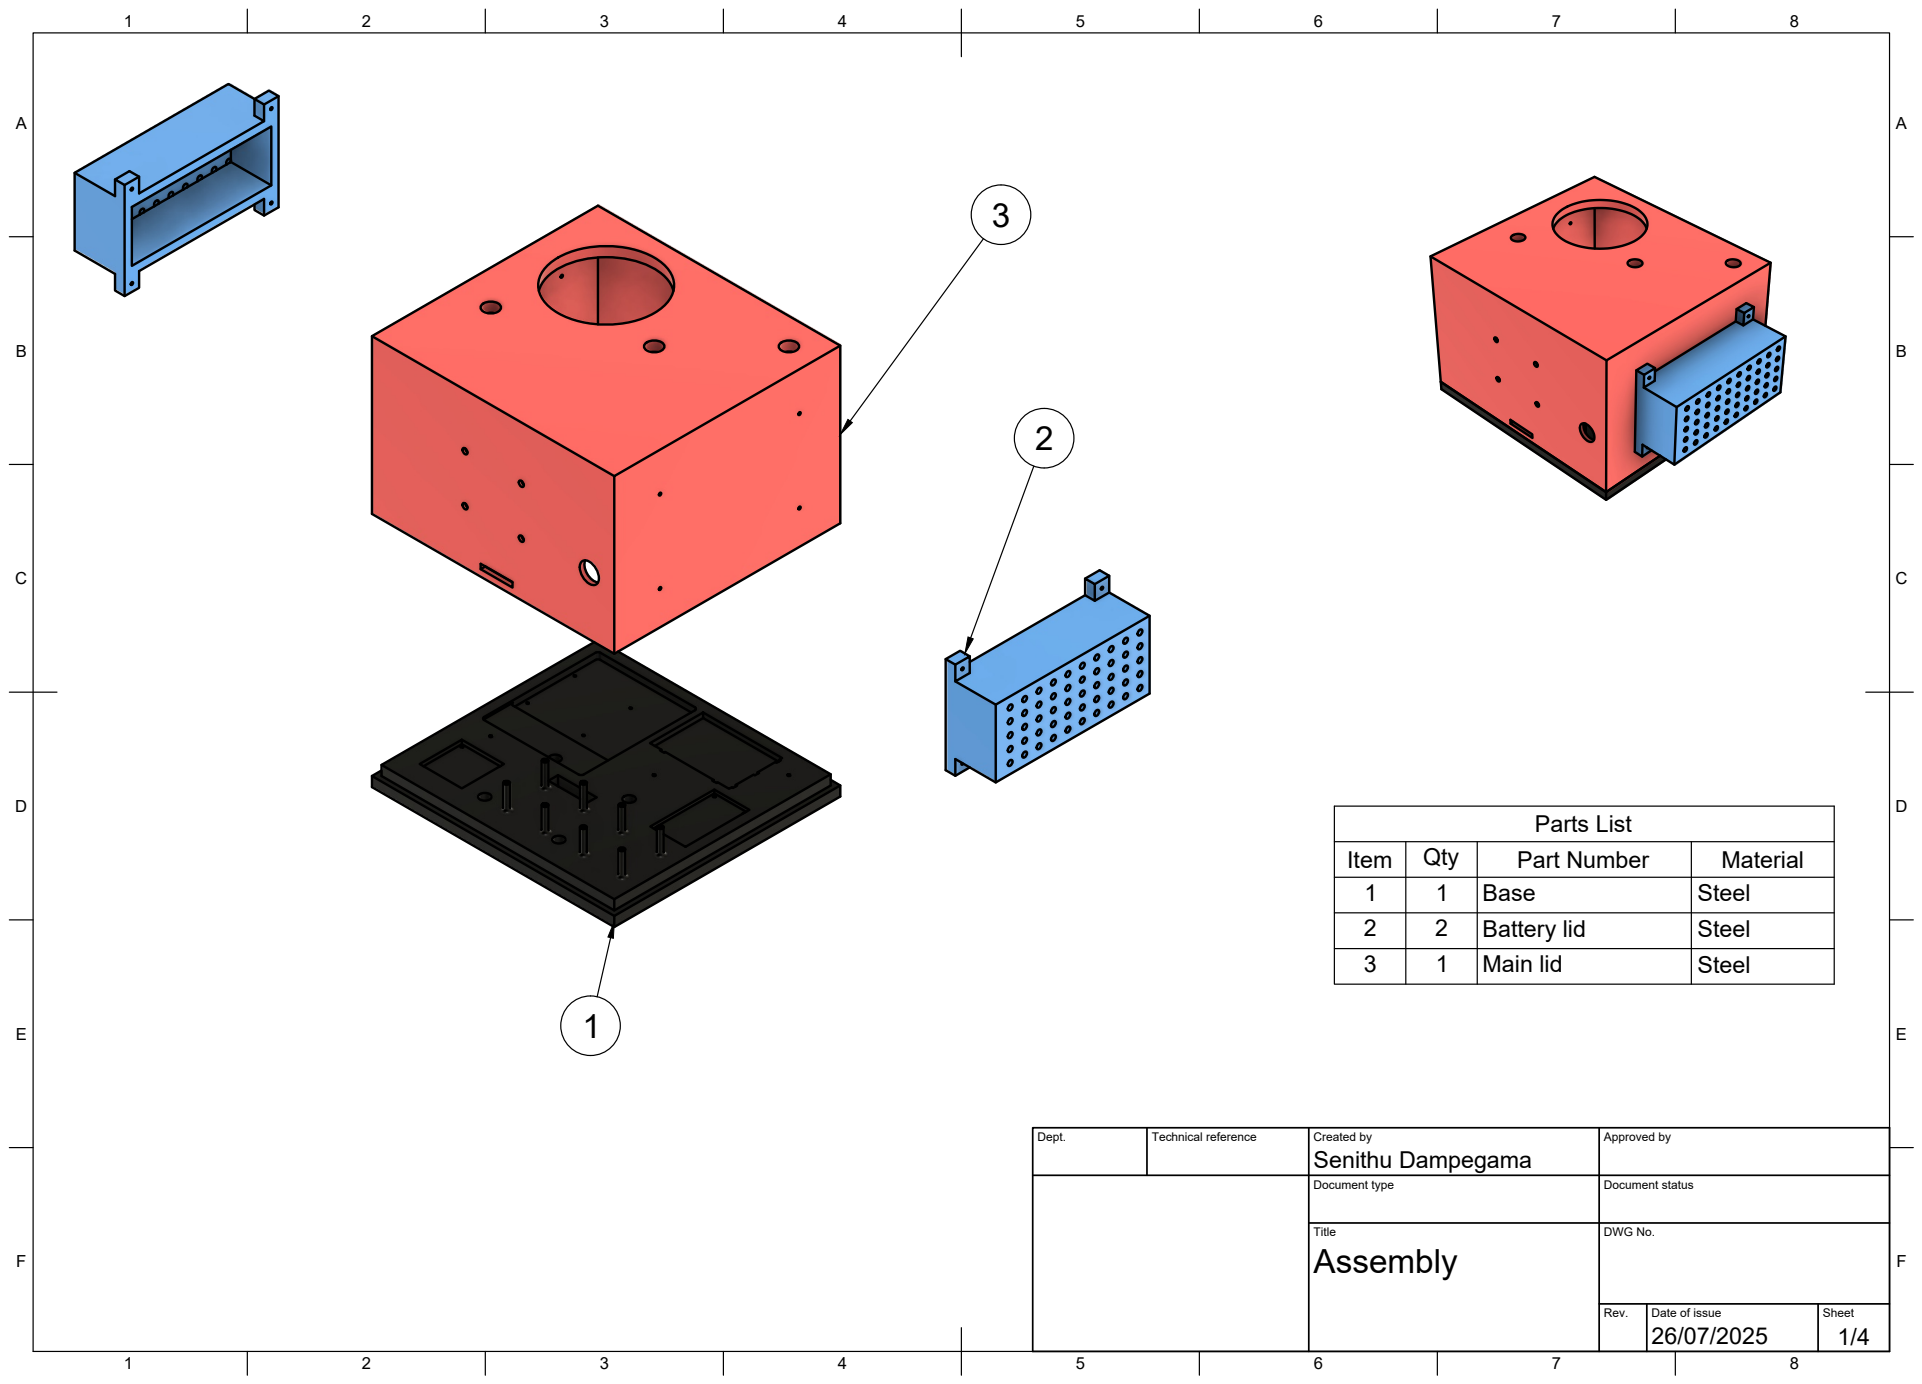
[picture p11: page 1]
Dept.; Technical reference; Created by; Approved by; Document type; Document status; Title; DWG No.; Rev.; Date of issue; Sheet; Assembly; Senithu Dampegama; Parts List; Item; Qty; Part Number; Material; Base; Steel; Battery lid; Main lid

A

A

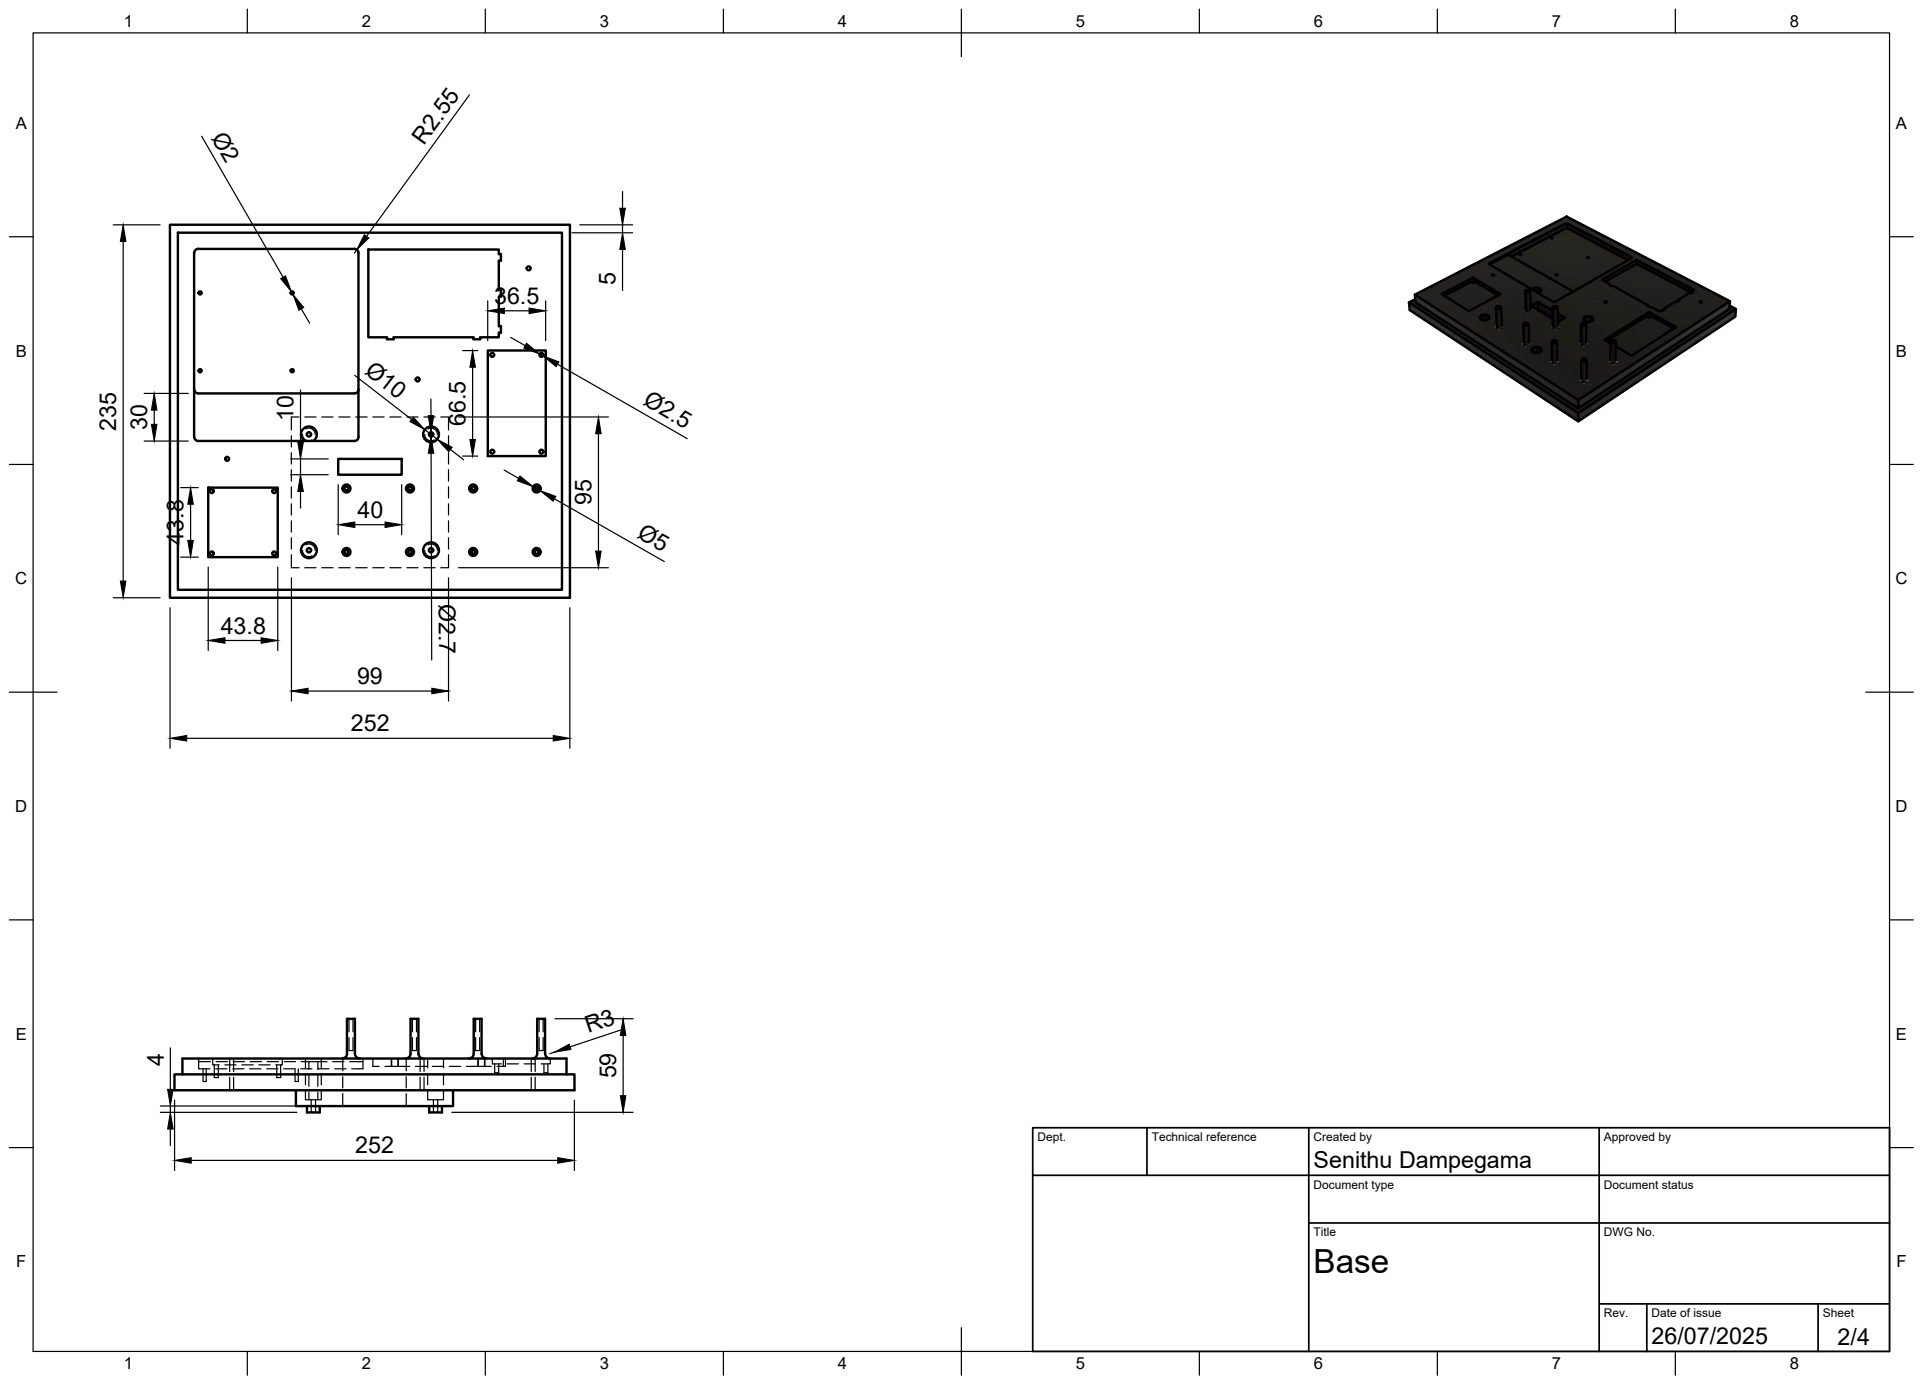
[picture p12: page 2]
Dept.; Technical reference; Created by; Approved by; Document type; Document status; Title; DWG No.; Base; Senithu Dampegama; 252 ²³⁵

A

A

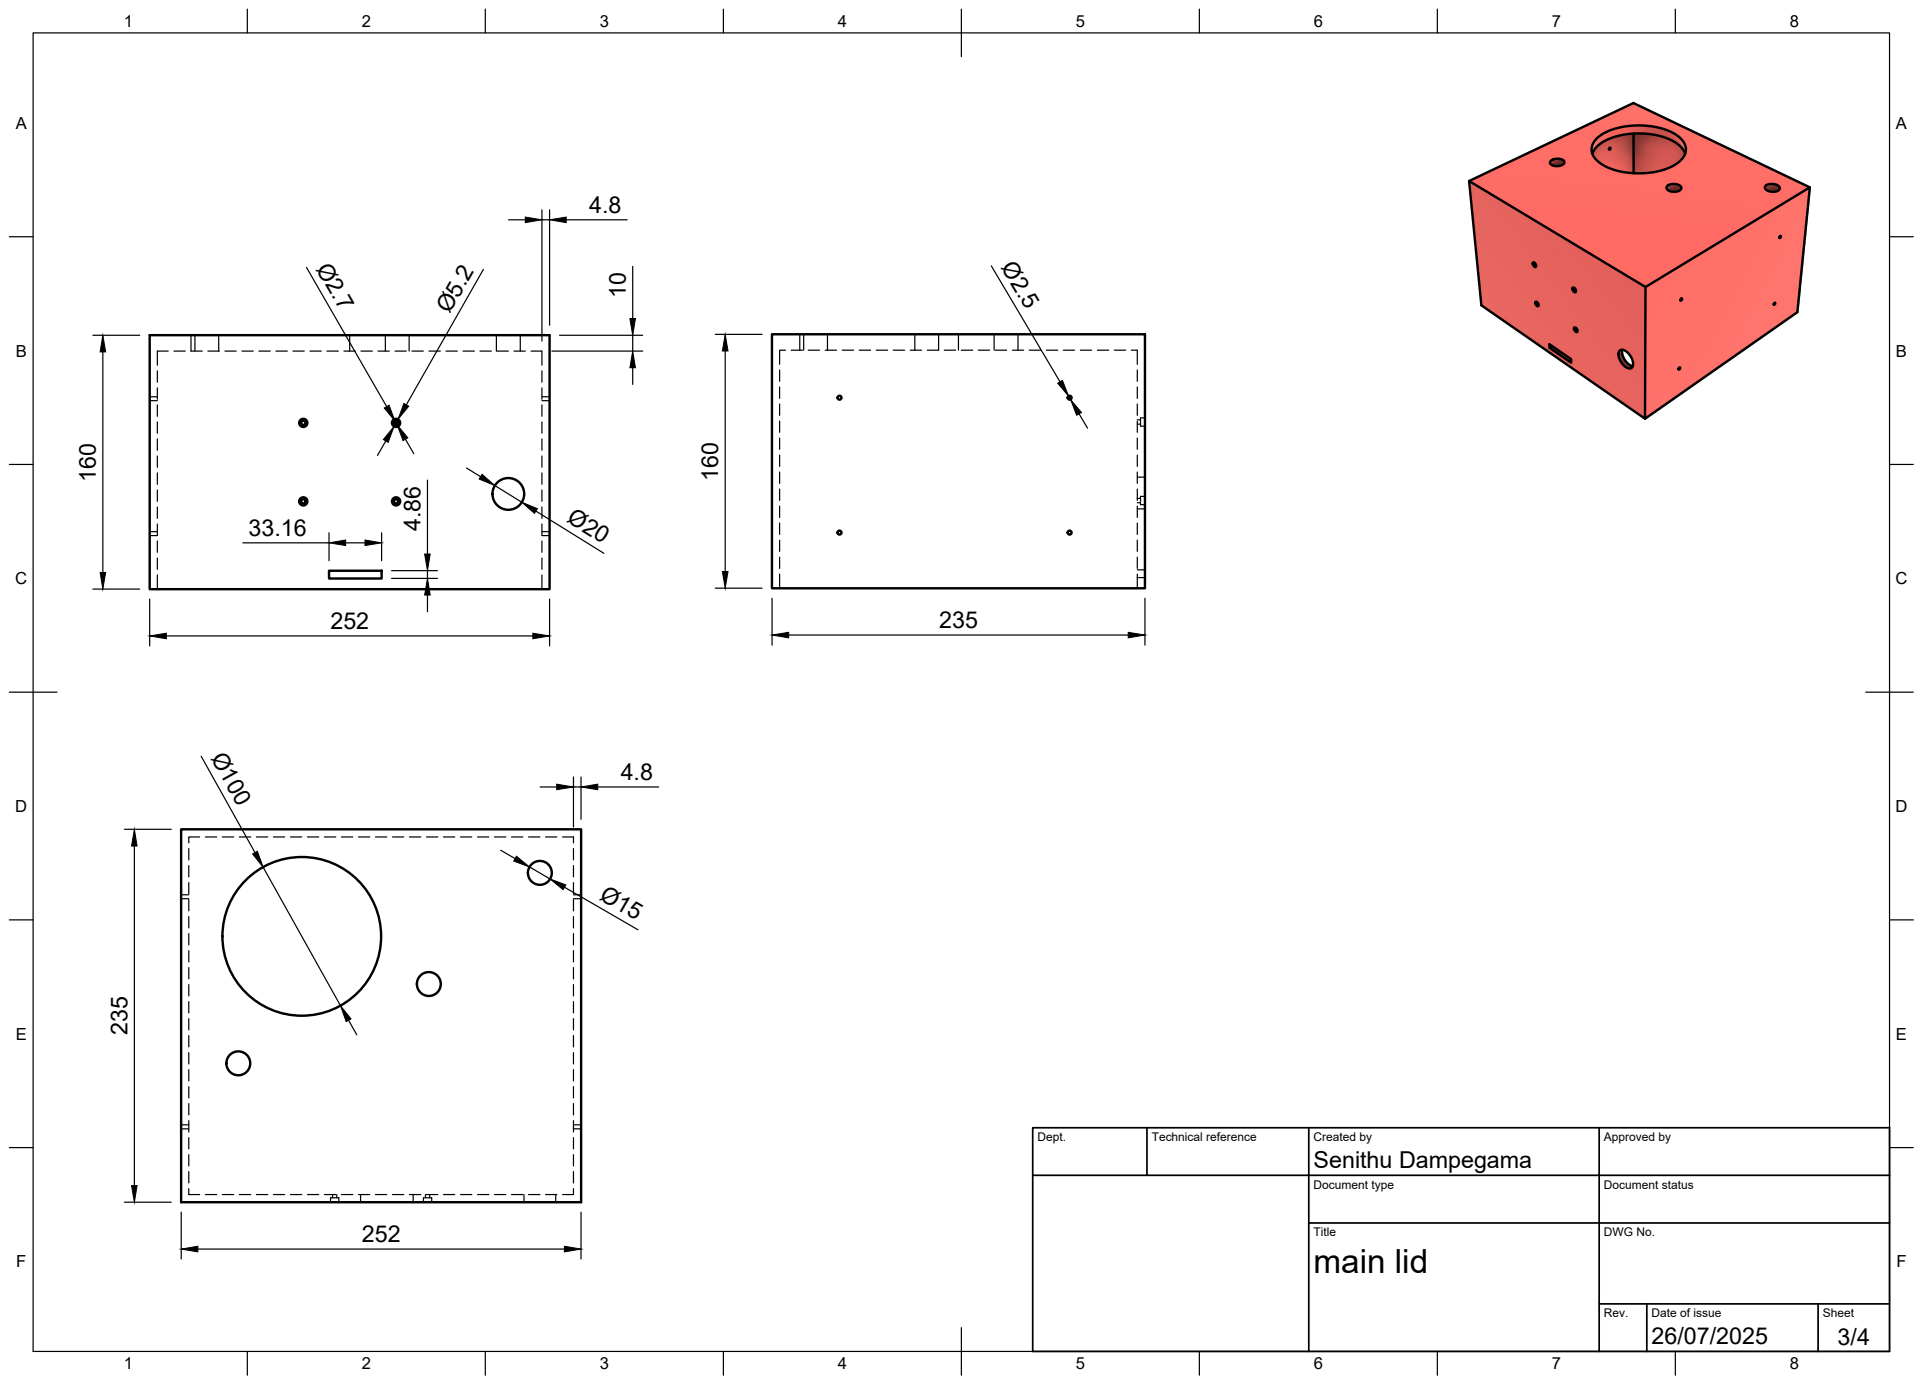
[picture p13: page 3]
Dept.; Technical reference; Created by; Approved by; Document type; Document status; Title; DWG No.; main lid; Senithu Dampegama; 252 ²³⁵; 252 ¹⁶⁰; 235 ¹⁶⁰

A

A

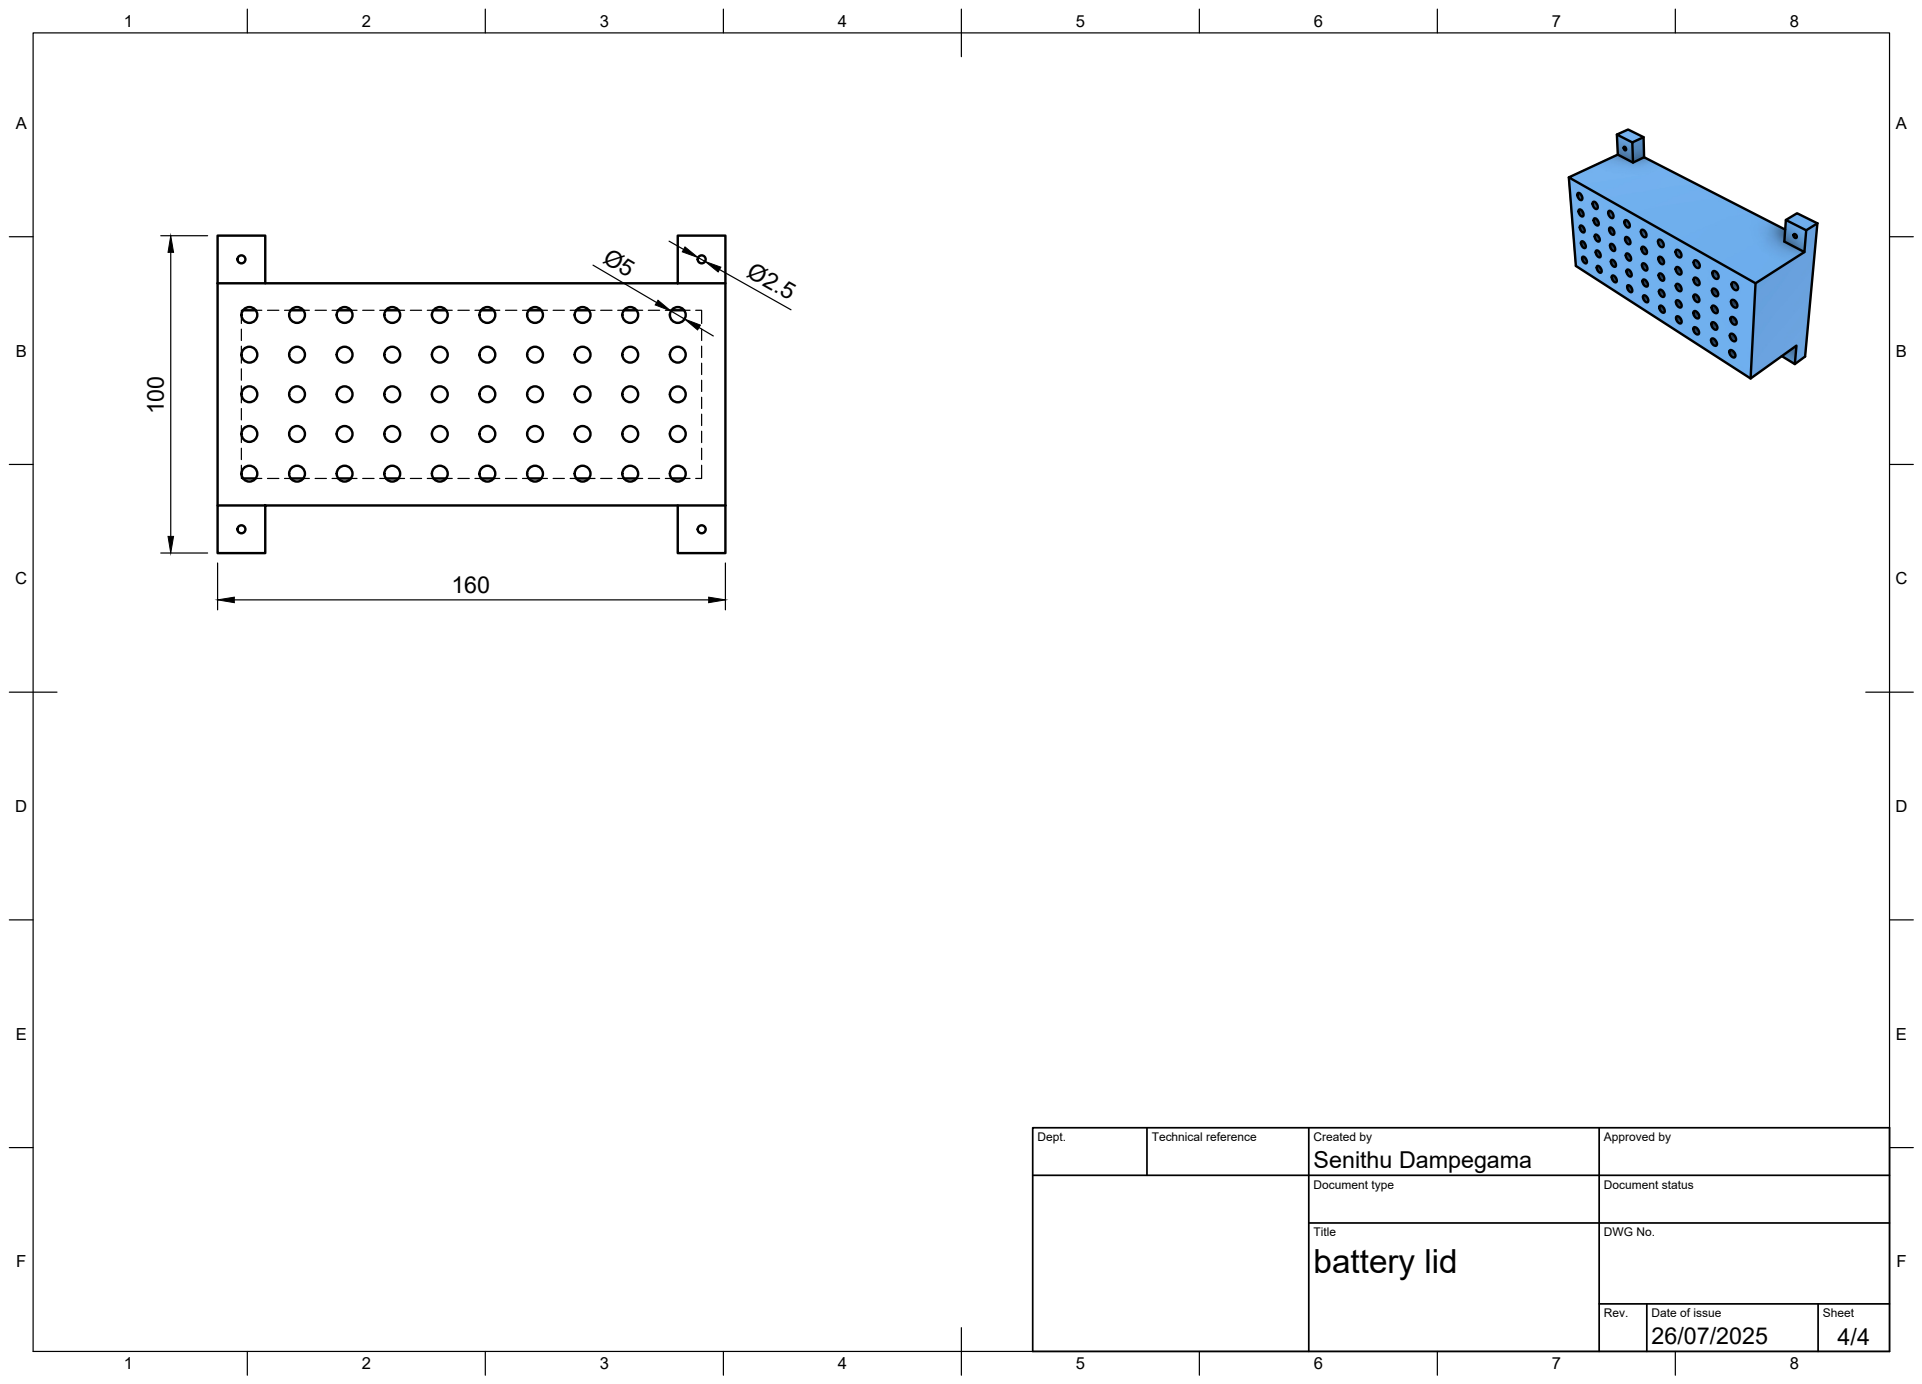
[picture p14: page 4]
Dept.; Technical reference; Created by; Approved by; Document type; Document status; Title; DWG No.; battery lid; Senithu Dampegama; 160 ¹⁰⁰

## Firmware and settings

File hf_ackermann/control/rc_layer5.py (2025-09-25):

#!/usr/bin/env python3
# -*- coding: utf-8 -*-
"""
Layer 5 — Decision Maker for Human-Follow (Ackermann crawler) with directional loss recovery
and optional target lock + depth-aware distance.

State machine: INIT → SEARCH → ACQUIRE → FOLLOW → FAULT

Vision interface (VisionBus.publish):
  - offset_x: float in [-1..+1]
  - area: float in [0..1]
  - quality: float in [0..1]
  - track_id: Optional[int]
  - z_m: Optional[float]  (meters; if provided and params.target_z_m is set, used for distance)

L4 contract: unchanged; we only call RcLayer4.send() with uppercase ASCII commands.
Cooldown gating is local to L5 and is NOT forwarded to L4.
"""

from __future__ import annotations
import time
import threading
from dataclasses import dataclass
from enum import Enum, auto
from typing import Optional, Dict, Any, Literal

# Local import within package
from .rc_layer4 import RcLayer4, L4Error, L4Disconnected


# ---------------------------- Parameters ----------------------------

@dataclass
class HFParams:
    # Steering (ARC)
    deadband_x: float = 0.16          # tuned defaults are provided by app
    k_arc_pwm:   int  = 700
    min_arc_pwm: int  = 120
    max_arc_pwm: int  = 220
    arc_impulse_ms: int = 180

    # Distance (DRIVE) — area based unless target_z_m is set and vision provides z_m
    target_area: float = 0.18
    area_tol:    float = 0.04
    k_drive_pwm: int   = 2200
    min_drive_pwm: int = 120
    max_drive_pwm: int = 190
    drive_impulse_ms: int = 240

    # Depth-based distance control (optional)
    target_z_m: Optional[float] = None    # if set, use z_m to regulate distance
    z_tol_m: float = 0.15                 # +/- tolerance window around target_z_m

    # Back-off when too close
    close_back_pwm: int = 140
    close_back_ms:  int = 150

    # Freshness & loop
    stale_ms:   int   = 300
    lost_ms:    int   = 700
    loop_hz:    float = 15.0
    cooldown_ms:int   = 90

    # Filters (1-pole IIR)
    tau_x_ms:   int = 180
    tau_area_ms:int = 220
    tau_z_ms:   int = 220

    # Logging
    verbose: bool = True

    # Directional recovery on loss
    recover_enable:      bool = True
    recover_max_ms:      int  = 3000
    recover_arc_pwm:     int  = 250
    recover_impulse_ms:  int  = 180
    recover_cooldown_ms: int  = 120
    recover_min_abs_x:   float = 0.10
    quality_gate:        float = 0.60

    # Turning shape & minimum
    arc_gamma: float = 1.6          # non-linearity exponent for |offset_x|
    pwm_turn_min: int = 140         # minimum PWM when we decide to turn

    # Asymmetric left/right gains and caps
    k_arc_pwm_left: int = 700
    k_arc_pwm_right: int = 820      # boost right
    arc_pwm_cap_left: int = 250
    arc_pwm_cap_right: int = 300    # allow a bit more on right
    arc_impulse_ms_left: int = 180
    arc_impulse_ms_right: int = 200 # slightly longer on right

    # Optional static bias (normalized units; + biases to right)
    steer_bias: float = 0.00

    # Search behavior: 'idle' (stationary) or 'peek' (legacy peeks). Default stationary.
    search_mode: Literal['idle', 'peek'] = 'idle'


# ---------------------------- Vision plumbing ----------------------------

@dataclass
class VisionSample:
    offset_x: float
    area:    float
    quality: float
    stamp_ms:int
    track_id: Optional[int] = None
    z_m: Optional[float] = None


class VisionBus:
    """
    Minimal thread-safe mailbox for the latest vision measurement.
    Camera adapter calls publish(); Layer 5 polls latest().
    """
    def __init__(self):
        self._lock = threading.Lock()
        self._latest: Optional[VisionSample] = None

    def publish(
        self,
        offset_x: float,
        area: float,
        quality: float,
        track_id: Optional[int] = None,
        z_m: Optional[float] = None,
    ):
        now_ms = int(time.monotonic() * 1000)
        sample = VisionSample(offset_x, area, quality, now_ms, track_id, z_m)
        with self._lock:
            self._latest = sample

    def latest(self) -> Optional[VisionSample]:
        with self._lock:
            return self._latest


# ---------------------------- Synthetic Vision (unchanged) ----------------------------

class SyntheticVision(threading.Thread):
    def __init__(self, bus: VisionBus, period_s: float = 0.05):
        super().__init__(daemon=True)
        self.bus = bus
        self.period_s = period_s
        self._stop_evt = threading.Event()

    def stop(self): self._stop_evt.set()

    def run(self):
        t0 = time.monotonic()
        while not self._stop_evt.is_set():
            t = time.monotonic() - t0
            offset_x = 0.25 * (1 if int(t) % 8 < 4 else -1) + 0.12 * (((t * 0.8) % 1.0) - 0.5) * 2
            area     = 0.06 + 0.02 * ((t * 0.3) % 1.0)
            quality  = 0.9
            self.bus.publish(offset_x, area, quality, track_id=None, z_m=None)
            time.sleep(self.period_s)


# ---------------------------- Layer 5 Controller ----------------------------

class Mode(Enum):
    INIT = auto()
    SEARCH = auto()
    ACQUIRE = auto()
    FOLLOW = auto()
    FAULT = auto()


def _clamp(v, lo, hi):
    return hi if v > hi else lo if v < lo else v


class Layer5(threading.Thread):
    """
    Decision layer. One command at a time via L4. Run as its own thread.
    """
    def __init__(self, l4: RcLayer4, vision: VisionBus, params: Optional[HFParams] = None):
        super().__init__(daemon=True)
        self.l4 = l4
        self.vision = vision
        self.p = params or HFParams()

        # internal state
        self.mode = Mode.INIT
        self._stop_evt = threading.Event()
        self._cooldown_until_ms = 0
        self._last_seen_ms = 0
        self._centered_once = False
        self._search_stopped = False

        # filters
        self._x_f = 0.0
        self._area_f = 0.0
        self._z_f: Optional[float] = None
        self._have_filter_seed = False

        # directional recovery memory
        self._last_good_x: float = 0.0         # sign tells last-seen side
        self._recover_active: bool = False
        self._recover_until_ms: int = 0        # wall-clock deadline for recovery peeks

        # target lock
        self._locked_id: Optional[int] = None

        # state entry timestamp (ms) for edge-trigger actions
        self._state_entry_ms: int = 0

        # FAULT/reconnect management
        self._reconnect_backoff_s: float = 1.0
        self._reconnect_next_ms: int = 0

    # --------- public API ---------
    def stop(self): self._stop_evt.set()

    def lock_target(self, track_id: Optional[int]):
        self._locked_id = int(track_id) if track_id is not None else None
        if self.p.verbose:
            print(f"[L5] lock_target → {self._locked_id}")

    def release_lock(self):
        if self.p.verbose and self._locked_id is not None:
            print(f"[L5] release_lock (was {self._locked_id})")
        self._locked_id = None

    def locked_id(self) -> Optional[int]:
        return self._locked_id

    # --------- helpers ---------

    def _now_ms(self) -> int:
        return int(time.monotonic() * 1000)

    def _iir(self, prev: float, new: float, tau_ms: int, dt_ms: int) -> float:
        if tau_ms <= 0 or dt_ms <= 0: return new
        a = dt_ms / (tau_ms + dt_ms)
        return (1 - a) * prev + a * new

    def _arc_pwm(self, abs_x: float) -> int:
        return int(_clamp(abs_x * self.p.k_arc_pwm, self.p.min_arc_pwm, self.p.max_arc_pwm))

    def _drive_pwm(self, err: float) -> int:
        return int(_clamp(err * self.p.k_drive_pwm, self.p.min_drive_pwm, self.p.max_drive_pwm))

    def _log(self, *a):
        if self.p.verbose: print(*a)

    # --- fixed: local cooldown override, never forwarded into L4 ---
    def _issue(self, cmd: str, *args, cooldown_override_ms: Optional[int] = None, **kw):
        """Single actuation to L4 with OK/DONE wait + cooldown (optionally overridden)."""
        try:
            res = self.l4.send(cmd, *args, **kw)     # do NOT pass the override into L4
            cool = self.p.cooldown_ms if (cooldown_override_ms is None) else int(cooldown_override_ms)
            self._cooldown_until_ms = self._now_ms() + max(0, cool)
            return res
        except L4Disconnected as e:
            self._log(f"[FAULT] L4 disconnected during {cmd}: {e}")
            self.mode = Mode.FAULT
            # schedule immediate reconnect attempt
            self._reconnect_backoff_s = 1.0
            self._reconnect_next_ms = self._now_ms()
            return None
        except L4Error as e:
            self._log(f"[FAULT] L4 error on {cmd}: {e}")
            self.mode = Mode.FAULT
            try:
                self.l4.send("stop")
            except Exception:
                pass
            return None

    # --------- main loop ---------

    def run(self):
        period_s = 1.0 / max(self.p.loop_hz, 1.0)
        last_loop_ms = self._now_ms()

        while not self._stop_evt.is_set():
            t_ms = self._now_ms()

            # Fetch latest vision
            m = self.vision.latest()
            fresh = False
            good = False
            if m:
                age = t_ms - m.stamp_ms
                fresh = (age <= self.p.stale_ms)
                good = fresh and (m.quality >= self.p.quality_gate)
                if self._locked_id is not None:
                    # Only accept measurements from the locked track
                    good = good and (m.track_id == self._locked_id)
                if good:
                    self._last_seen_ms = t_ms

                    # seed filters on first sample
                    if not self._have_filter_seed:
                        self._x_f, self._area_f = m.offset_x, m.area
                        self._z_f = m.z_m if m.z_m is not None else None
                        self._have_filter_seed = True

                    # update filters
                    dt_ms = max(t_ms - last_loop_ms, 1)
                    self._x_f    = self._iir(self._x_f,    m.offset_x, self.p.tau_x_ms,    dt_ms)
                    self._area_f = self._iir(self._area_f, m.area,     self.p.tau_area_ms, dt_ms)
                    if m.z_m is not None:
                        self._z_f = self._iir(self._z_f if self._z_f is not None else m.z_m,
                                              m.z_m, self.p.tau_z_ms, dt_ms)

                    # remember last-good side
                    self._last_good_x = self._x_f

            # Loss detection (FOLLOW/ACQUIRE → SEARCH + center + arm recovery)
            if self.mode in (Mode.FOLLOW, Mode.ACQUIRE):
                if t_ms - self._last_seen_ms > self.p.lost_ms:
                    self._log("[SEARCH] Lost target → entering SEARCH (stationary)")
                    self.mode = Mode.SEARCH
                    self._state_entry_ms = 0  # force edge-trigger actions
                    self._centered_once = False
                    self._search_stopped = False
                    # ignore recovery when in stationary mode
                    self._recover_active = False

            # Cooldown gate
            if t_ms < self._cooldown_until_ms:
                time.sleep(0.002)
                last_loop_ms = t_ms
                continue

            # ---------------- State machine ----------------
            if self.mode == Mode.INIT:
                self._log("[INIT] Centering, then SEARCH")
                self._issue("stop")
                self._issue("center")
                self.mode = Mode.SEARCH
                self._state_entry_ms = 0
                self._search_stopped = False
                self._recover_active = False

            elif self.mode == Mode.SEARCH:
                # Edge-triggered stop+center on entering SEARCH
                if self._state_entry_ms == 0:
                    self._log("[SEARCH] stationary (stop+center)")
                    self._issue("stop")
                    self._issue("center")
                    self._state_entry_ms = t_ms
                    self._centered_once = True
                    self._search_stopped = True

                # Stationary SEARCH: no motion. Transition only when good target seen.
                if good:
                    self._log("[ACQUIRE] target seen")
                    self._search_stopped = False
                    self._recover_active = False
                    self.mode = Mode.ACQUIRE

            elif self.mode == Mode.ACQUIRE:
                if not good:
                    self._log("[SEARCH] Lost during acquire → SEARCH (stationary)")
                    self.mode = Mode.SEARCH
                    self._state_entry_ms = 0
                    self._search_stopped = False
                    self._recover_active = False
                else:
                    # Nudge heading toward target
                    pwm = self._arc_pwm(abs(self._x_f))
                    dir_cmd = "arcleft" if self._x_f < 0 else "arcright"
                    self._log(f"[ACQUIRE] {dir_cmd} pwm={pwm}")
                    self._issue(dir_cmd, pwm, self.p.arc_impulse_ms, end="U")

                    # Distance control (prefer depth if enabled)
                    if self.p.target_z_m is not None and self._z_f is not None:
                        err = self.p.target_z_m - float(self._z_f)
                        if err > self.p.z_tol_m:
                            fwd = self._drive_pwm(err)
                            self._log(f"[ACQUIRE] forward (z) pwm={fwd}")
                            self._issue("driveforward", fwd, self.p.drive_impulse_ms)
                    else:
                        err = self.p.target_area - self._area_f
                        if err > self.p.area_tol:
                            fwd = self._drive_pwm(err)
                            self._log(f"[ACQUIRE] forward (area) pwm={fwd}")
                            self._issue("driveforward", fwd, self.p.drive_impulse_ms)

                    self.mode = Mode.FOLLOW

            elif self.mode == Mode.FOLLOW:
                if not good:
                    # stale → stop once, maybe center once
                    if not self._search_stopped:
                        self._issue("stop")
                        self._search_stopped = True
                    if not self._centered_once:
                        self._log("[FOLLOW] stale → center once")
                        self._issue("center")
                        self._centered_once = True
                    # Note: recovery arming happens in the loss block above
                else:
                    self._centered_once = False
                    self._search_stopped = False

                    # Priority 1: steering
                    side, pwm, impulse_ms = self._turn_cmd_from_offset(self._x_f)
                    if side == "R":
                        self._log(f"[FOLLOW] steer arcright pwm={pwm}")
                        self._issue("arcright", pwm, impulse_ms, end="U")
                    elif side == "L":
                        self._log(f"[FOLLOW] steer arcleft pwm={pwm}")
                        self._issue("arcleft", pwm, impulse_ms, end="U")
                    else:
                        # Priority 2: distance
                        if self.p.target_z_m is not None and self._z_f is not None:
                            err = self.p.target_z_m - float(self._z_f)
                            if err > self.p.z_tol_m:
                                pwm = self._drive_pwm(err)
                                self._log(f"[FOLLOW] forward (z) pwm={pwm}")
                                self._issue("driveforward", pwm, self.p.drive_impulse_ms)
                            elif err < -self.p.z_tol_m:
                                self._log(f"[FOLLOW] back (z) pwm={self.p.close_back_pwm}")
                                self._issue("driveback", self.p.close_back_pwm, self.p.close_back_ms)
                            else:
                                if not self._centered_once:
                                    self._log("[FOLLOW] in band → center")
                                    self._issue("center")
                                    self._centered_once = True
                        else:
                            err = self.p.target_area - self._area_f
                            if err > self.p.area_tol:
                                pwm = self._drive_pwm(err)
                                self._log(f"[FOLLOW] forward (area) pwm={pwm}")
                                self._issue("driveforward", pwm, self.p.drive_impulse_ms)
                            elif err < -self.p.area_tol:
                                self._log(f"[FOLLOW] back (area) pwm={self.p.close_back_pwm}")
                                self._issue("driveback", self.p.close_back_pwm, self.p.close_back_ms)
                            else:
                                if not self._centered_once:
                                    self._log("[FOLLOW] in band → center")
                                    self._issue("center")
                                    self._centered_once = True

            elif self.mode == Mode.FAULT:
                # Periodically attempt to reopen the port with exponential backoff
                if self._reconnect_next_ms == 0:
                    self._reconnect_backoff_s = 1.0
                    self._reconnect_next_ms = t_ms
                if t_ms >= self._reconnect_next_ms:
                    self._log("[FAULT] Attempting L4 reconnect…")
                    port = None
                    try:
                        port = self.l4._reopen(prefer_last=True)
                    except Exception:
                        port = None
                    if port:
                        self._log(f"[FAULT] Reconnected on {port}; resyncing")
                        # Best-effort resync
                        try:
                            self.l4.send("stop")
                            self.l4.send("center")
                        except Exception:
                            pass
                        # Clear lock, transition to SEARCH (stationary)
                        self.release_lock()
                        self.mode = Mode.SEARCH
                        self._state_entry_ms = 0
                        self._search_stopped = False
                        self._recover_active = False
                        # reset backoff for future
                        self._reconnect_backoff_s = 1.0
                        self._reconnect_next_ms = 0
                    else:
                        # schedule next attempt
                        self._reconnect_backoff_s = min(10.0, max(1.0, self._reconnect_backoff_s * 2.0))
                        self._reconnect_next_ms = t_ms + int(self._reconnect_backoff_s * 1000)
                # Small sleep to avoid busy loop
                time.sleep(0.05)

            last_loop_ms = t_ms
            time.sleep(period_s)

    # --------- steering helper (FOLLOW only) ---------
    def _turn_cmd_from_offset(self, offx: float) -> tuple[str, int, int]:
        """
        Map normalized horizontal offset [-1..+1] to (side, pwm, impulse_ms).
        Uses deadband, bias, non-linear gamma, min PWM, and asymmetric left/right caps.
        Returns: ("L" or "R", pwm, impulse_ms) or ("", 0, 0) if within deadband.
        """
        # Apply optional bias
        try:
            offx = float(offx) + float(self.p.steer_bias)
        except Exception:
            offx = float(offx)

        # Deadband
        if abs(offx) <= self.p.deadband_x:
            return ("", 0, 0)

        # Normalize magnitude beyond deadband to [0..1]
        mag = (abs(offx) - self.p.deadband_x) / max(1e-6, 1.0 - self.p.deadband_x)
        # Non-linear shaping
        mag = max(0.0, min(1.0, mag)) ** float(self.p.arc_gamma)

        if offx > 0:
            # RIGHT turn
            base = int(self.p.k_arc_pwm_right * mag)
            pwm = max(int(self.p.pwm_turn_min), min(int(self.p.arc_pwm_cap_right), base))
            return ("R", pwm, int(self.p.arc_impulse_ms_right))
        else:
            # LEFT turn
            base = int(self.p.k_arc_pwm_left * mag)
            pwm = max(int(self.p.pwm_turn_min), min(int(self.p.arc_pwm_cap_left), base))
            return ("L", pwm, int(self.p.arc_impulse_ms_left))


# ---------------------------- Inline demo (legacy) ----------------------------
if __name__ == "__main__":
    # Legacy in-module demo kept for convenience; new app CLI is hf_ackermann.app
    l4 = RcLayer4()
    try:
        l4.open()
        bus = VisionBus()
        synth = SyntheticVision(bus, period_s=0.05)
        synth.start()
        params = HFParams(verbose=True)
        l5 = Layer5(l4, bus, params)
        l5.start()
        while True:
            time.sleep(0.2)
    except KeyboardInterrupt:
        pass
    finally:
        try:
            l5.stop(); l5.join(timeout=1.0)
        except Exception:
            pass
        try:
            synth.stop(); synth.join(timeout=1.0)
        except Exception:
            pass
        try:
            l4.close()
        except Exception:
            pass

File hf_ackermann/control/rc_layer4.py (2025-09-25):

#!/usr/bin/env python3
# -*- coding: utf-8 -*-
"""
Layer 4 (Jetson-side) control for your Layer 3 serial protocol.

WHAT THIS PROVIDES
- Single-call API: l4.send("arcright", 255, 500)  → sends "ARC R 255 500 U"
  and blocks until the firmware replies OK/DONE (with robust timeouts).
- Command aliases & argument validation.
- Built-in ACK/DONE handling; ERR raises an exception.
- Optional telemetry callback (receives parsed TELEM dicts).
- Auto port detection for Teensy; or set PORT manually.

BASIC USAGE
-----------
from rc_layer4 import RcLayer4

l4 = RcLayer4()           # auto-detects Teensy port, 115200 baud
l4.open()

# examples:
l4.send("steerleft")                 # OK STEER
l4.send("driveforward", 200, 1500)   # OK DRIVE ... DONE DRIVE
l4.send("arcright", 255, 500)        # OK ARC   ... DONE ARC (auto-unlock)
l4.send("center")                    # OK CENTER
l4.send("stop")                      # OK STOP

l4.close()

NOTES
-----
- For drive/arc you pass (pwm, duration_ms). For arc you can also pass end="H" to hold lock.
  Example: l4.send("arcleft", 180, 2000, end="H")
- Default timeout for DONE is max( duration_ms + 2500ms, 6s ). Adjust per call via timeout=.
- Telemetry lines from Layer 3 are ignored unless you pass telemetry_cb= in constructor.
- You can also call convenience helpers: l4.arcright(255,500), l4.driveforward(180,2000), etc.
"""

import time
from typing import Optional, Callable, Dict, Any, Tuple, List

try:
    import serial
    from serial.tools import list_ports
except ImportError as e:
    raise SystemExit("pyserial missing. Install with: pip install pyserial") from e


# ---------------------------- configuration defaults ----------------------------

_DEFAULT_BAUD = 115200
_DEFAULT_READ_TIMEOUT = 0.05   # seconds; used for non-blocking-ish line reads
_DEFAULT_ACK_TIMEOUT = 2.0     # seconds; waiting for OK/ERR
_MIN_DONE_TIMEOUT = 6.0        # seconds; minimum DONE wait
_DONE_FUDGE_MS = 2500          # ms extra on top of commanded duration


# ---------------------------- utilities ----------------------------

def _find_teensy_port() -> Optional[str]:
    """
    Try to find a Teensy-like port. Preference for 'Teensy' in description,
    otherwise first USB-serial-ish candidate.
    """
    candidates: List[Tuple[str, str]] = []
    for p in list_ports.comports():
        desc = f"{p.manufacturer or ''} {p.product or ''} {p.description or ''}".strip()
        if "Teensy" in desc:
            return p.device
        if any(k in (desc or "").lower() for k in ["usb", "serial", "tty", "acm", "usbmodem"]):
            candidates.append((p.device, desc))
    return candidates[0][0] if candidates else None


class L4Error(RuntimeError):
    """Raised for device ERR replies or protocol timeouts."""


class L4PortError(Exception):
    """Base for Layer-4 port-level errors (disconnects, I/O)."""


class L4Disconnected(L4PortError):
    """Raised when the serial link drops (USB disconnect / re-enumeration)."""


# ---------------------------- the Layer 4 client ----------------------------

class RcLayer4:
    """
    High-level Layer 4 client: one-call `send()` that maps your friendly command names
    to the Layer 3 wire protocol, waits for OK/DONE, validates args, and raises on errors.
    """

    def __init__(
        self,
        port: Optional[str] = None,
        baud: int = _DEFAULT_BAUD,
        telemetry_cb: Optional[Callable[[Dict[str, Any]], None]] = None
    ):
        """
        :param port: Serial port (e.g., 'COM7' or '/dev/ttyACM0'). If None, auto-detect.
        :param baud: Baud rate (Layer 3 uses 115200 by default).
        :param telemetry_cb: Optional callback receiving parsed TELEM dicts.
        """
        self._cfg_port = port
        self._baud = baud
        self._ser: Optional[serial.Serial] = None
        self._telemetry_cb = telemetry_cb
        self._connected: bool = False
        self._port_path: Optional[str] = None

    # ---------- lifecycle ----------

    def open(self):
        """Open the serial port (auto-detect if needed) and flush input."""
        if self._ser and self._ser.is_open:
            return
        port = self._cfg_port or _find_teensy_port()
        if not port:
            raise L4Error("Could not auto-detect Teensy port. Pass port= to RcLayer4().")
        try:
            self._ser = serial.Serial(port=port, baudrate=self._baud, timeout=_DEFAULT_READ_TIMEOUT)
        except Exception as e:
            self._connected = False
            raise
        # give MCU a moment in case it resets-on-open
        time.sleep(0.5)
        self._flush_input()
        self._connected = True
        self._port_path = port

    def close(self):
        """Close the serial port."""
        try:
            if self._ser:
                try:
                    self._ser.close()
                except Exception:
                    pass
        finally:
            self._ser = None
            self._connected = False

    # ---------- connection helpers ----------

    def is_connected(self) -> bool:
        return bool(self._connected and self._ser and self._ser.is_open)

    def _safe_disconnect(self):
        try:
            if self._ser:
                try:
                    self._ser.close()
                except Exception:
                    pass
        finally:
            self._ser = None
            self._connected = False

    def _reopen(self, prefer_last: bool = True) -> Optional[str]:
        """Attempt to reopen the serial port. Returns the port path on success; None on failure."""
        candidates: List[str] = []
        if prefer_last and self._port_path:
            candidates.append(self._port_path)
        # Prefer Teensy-identified port
        p = _find_teensy_port()
        if p and p not in candidates:
            candidates.append(p)
        # Also include any device paths that look serial-ish (best effort)
        try:
            from serial.tools import list_ports
            for c in list_ports.comports():
                desc = f"{c.device} {c.description or ''} {c.manufacturer or ''}"
                if "teensy" in desc.lower() and c.device not in candidates:
                    candidates.append(c.device)
        except Exception:
            pass

        for devpath in candidates:
            try:
                self._ser = serial.Serial(port=devpath, baudrate=self._baud, timeout=_DEFAULT_READ_TIMEOUT)
                time.sleep(0.3)
                self._flush_input()
                self._connected = True
                self._port_path = devpath
                # Best-effort resync; ignore any error
                try:
                    self.send("stop")
                    self.send("center")
                except Exception:
                    pass
                return devpath
            except Exception:
                self._safe_disconnect()
                continue
        return None

    # ---------- public: single-call API ----------
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
